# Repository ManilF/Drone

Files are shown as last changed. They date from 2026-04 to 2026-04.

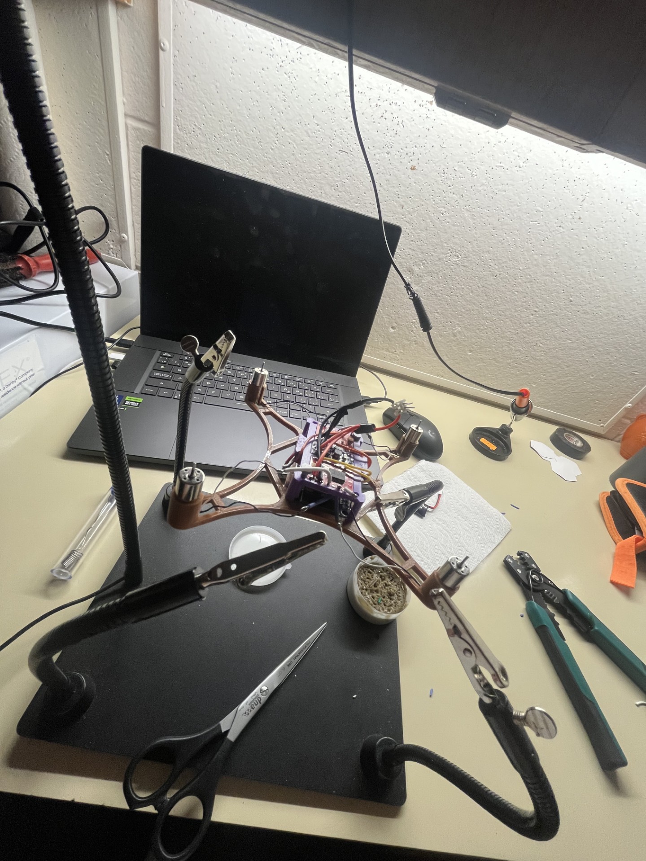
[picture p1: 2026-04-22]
Project_Gallery/image1.jpg

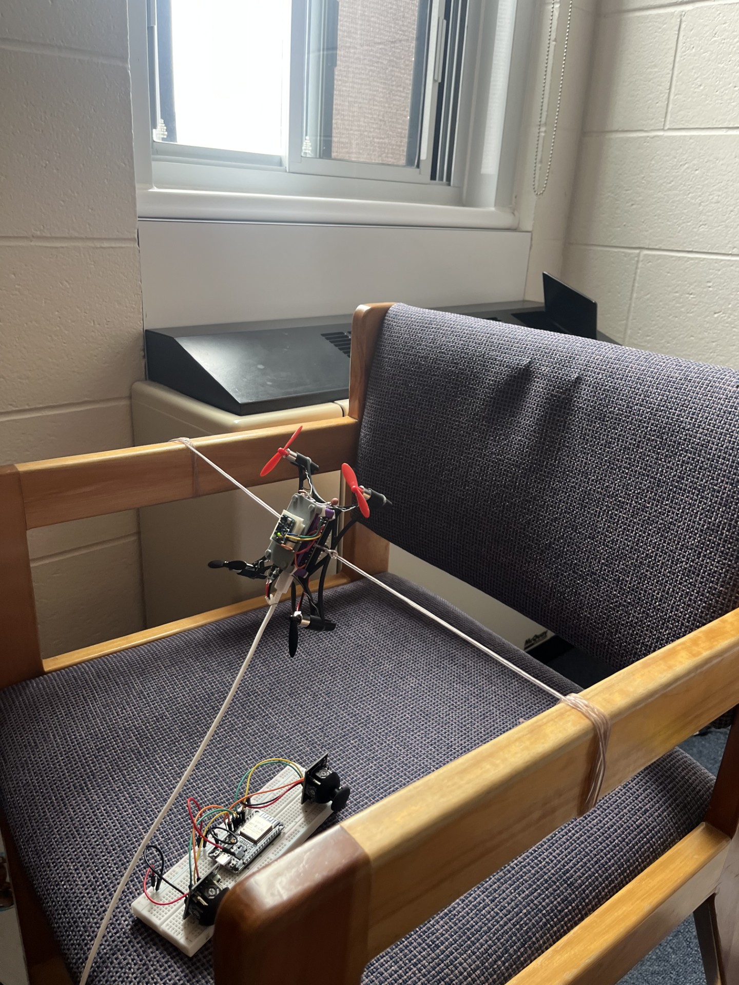
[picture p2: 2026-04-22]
Project_Gallery/image2.jpg

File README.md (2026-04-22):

# ESP32 Brushed Quadcopter

A full flight controller, a full RC radio link, and a complete ground telemetry system — built from two $5 ESP32 chips, with no flight-controller firmware, no RC receiver, no ESCs, and no external libraries beyond the ESP32 Arduino core.

Total electronics cost: **under $30**. Total code: **two `.cpp` files**. Madgwick AHRS, PID, mixer, radio protocol, all written from scratch and readable in an afternoon.

## Why This Project Is Unusual

A typical hobby quad stack is a $200+ pile of black boxes: a dedicated flight controller running Betaflight (half a million lines of C), an ELRS / Crossfire RC transmitter and receiver, four brushless ESCs running BLHeli, an OSD chip, an optional telemetry radio. You flash firmware, tune PIDs in a GUI, and learn nothing about what's actually happening inside.

This project replaces all of it with two generic WiFi microcontrollers:

| Part of the stack | Typical approach | This project |
|---|---|---|
| Flight controller | F4/F7 board + Betaflight | $5 ESP32, 1600 lines of `.cpp` |
| RC transmitter | $50–200 TX module | $5 ESP32 + 2 joysticks |
| RC protocol | ELRS / CRSF / SBUS | ESP-NOW (WiFi broadcast) |
| Receiver | Separate radio module | Same ESP32 as the FC |
| ESCs | 4x brushless ESCs, $15–30 | 2x TB6612FNG H-bridges, $2 each |
| Sensor fusion | Library / DMP | Inline Madgwick 6DOF (100 lines) |
| Telemetry | Extra hardware or none | Bidirectional over the same ESP-NOW link |

Because ESP-NOW is built into the ESP32's WiFi radio, the entire control **and** telemetry link is a software feature of the processor that was already there for IoT. Sub-millisecond latency, ~200 m line-of-sight range, no pairing ceremony, and you can OTA-reflash both ends over the same radio.

The full story (including why the educational value matters and what this unlocks): see `05_Ideas/esp32-drone-novelty-2026-04-20.md` in the Obsidian vault.

## Repository Layout

- `TX_Final.cpp` — controller / transmitter firmware
- `RX_Final.cpp` — drone / receiver firmware (the flight controller)
- `MadgwickAHRS.c` — reference implementation kept for comparison (not compiled into the flight controller — the drone uses its own inline 6DOF version)
- `CLAUDE.md` — implementation notes and “do not touch” list
- `TESTING_PLAN.md` — step-by-step PID tuning procedure

Each `.cpp` file is a standalone Arduino sketch. There is no multi-file build. Flash `TX_Final.cpp` to the controller ESP32, flash `RX_Final.cpp` to the drone ESP32.

## Hardware

### Bill of Materials (approx.)

| Part | Qty | Cost |
|---|---|---|
| ESP32 DevKit V1 | 2 | ~$10 |
| GY-87 (MPU6050 6-DOF IMU) | 1 | ~$3 |
| TB6612FNG H-bridge breakout | 2 | ~$4 |
| Brushed coreless motor (8520) | 4 | ~$4 |
| 1S LiPo (350–500 mAh) | 1 | ~$5 |
| 2x analog thumb joystick with switch | — | ~$3 |
| Frame (3D-printed or foam) + props | — | ~$2 |
| **Total** | | **~$31** |

### Drone wiring

- I2C: **SDA = GPIO22, SCL = GPIO21** (swapped vs. ESP32 default; matches this build)
- Motors via TB6612FNG:
  - M1 → **GPIO25** (front-left)
  - M2 → **GPIO26** (front-right)
  - M3 → **GPIO27** (back-right)
  - M4 → **GPIO14** (back-left)
- TB6612 STBY (both boards tied together) → **GPIO33**, with a 10 kΩ pull-down to ground so motors stay disabled during boot

### Controller wiring

All joystick axes must be on ADC1 pins — ADC2 is unusable while WiFi is active on ESP32.

| Input | GPIO |
|---|---|
| Throttle axis | 33 |
| Yaw axis | 32 |
| Pitch axis | 35 |
| Roll axis | 34 |
| Left stick switch (L_SW) | 26 |
| Right stick switch (R_SW) | 27 |
| Status LED (optional) | 2 |

## Radio Link — ESP-NOW

The drone and controller are paired by hard-coding each other’s MAC addresses.

- In `TX_Final.cpp`: `receiverMac[]` = **drone** MAC
- In `RX_Final.cpp`: `CONTROLLER_MAC[]` = **controller** MAC

First-time pairing:

1. Flash both boards once with placeholder MACs.
2. Open Serial Monitor on each at 115200 baud; the boards print their own MAC at boot.
3. Paste the drone MAC into `TX_Final.cpp` and the controller MAC into `RX_Final.cpp`.
4. Reflash.

### Packet structures

Both structs are `__attribute__((packed))` and must match byte-for-byte across both files.

- `ControlPacket` (15 bytes): `t_ms`, `armed`, `calibrate_level`, `thr (0..1000)`, `yaw/pitch/roll (-500..500)`
- `TelemetryPacket` (30 bytes): IMU angles, PID outputs, all four motor duties, accel magnitude, arming/standby state, packet age

Control packets are sent at 50 Hz; telemetry at 20 Hz. The drone disarms automatically if no valid control packet arrives for **250 ms** (failsafe).

## Firmware Architecture

### Drone main loop — 500 Hz

```
getCommandsFromEspNow()   // pull latest control packet, apply failsafe
  → getIMUdata()          // raw I2C, bias correct, LPF
  → Madgwick6DOF()        // quaternion fusion with accel-trust gating
  → getDesState()         // sticks → desired roll/pitch angles + yaw rate
  → controlANGLE()        // PID: angle mode for roll/pitch, rate mode for yaw
  → mixerQuad()           // quad-X mixer with per-motor spin sign
  → scaleToDuty()         // 0..1 → 0..255 PWM duty
  → throttleCutAndCommand()  // arm/failsafe check, write PWM
  → sendTelemetry()
```

### Control strategy

- **Roll / Pitch**: angle-mode PID. Desired state is an absolute angle in degrees. Derivative-on-measurement (uses raw gyro, not error derivative) — avoids derivative kick on setpoint changes.
- **Yaw**: rate-mode PID. Desired state is a rotation rate in deg/s. This is standard for quads because yaw has no gravity reference and you want to allow continuous spins.
- **Anti-windup**: integrators reset when throttle < 1060 (drone grounded).
- **Adaptive Madgwick beta**: normally 0.06 while armed (vibration-tolerant). When the estimator drifts >5° from the accel-only attitude and the accel reads ~1 g, beta boosts to 0.20 for fast recovery, then ramps back down.

### Mixer

```cpp
m1 = T - P + R + (M1_SPIN * Y);   // front-left
m2 = T - P - R + (M2_SPIN * Y);   // front-right
m3 = T + P - R + (M3_SPIN * Y);   // back-right
m4 = T + P + R + (M4_SPIN * Y);   // back-left
```

`M1_SPIN..M4_SPIN` are compile-time constants (`MOTOR_SPIN_CW = -1`, `MOTOR_SPIN_CCW = +1`). The default configuration is:

- M1 (FL), M3 (BR) = **CW** viewed from above
- M2 (FR), M4 (BL) = **CCW** viewed from above

If your physical motors spin the other way, **change only these four constants** — do not rewrite the mixer. Yaw authority and sign correctness follow automatically.

## Calibration

### Startup calibration (every boot)

Drone sits still for ~3 seconds after power-on. The firmware averages 800 IMU samples to compute gyro bias and accel bias along the measured gravity direction. It does **not** assume the frame is perfectly level — it only pulls the resting accel magnitude toward 1.00 g.

Keep the drone still on a flat surface during the boot LED-blink sequence.

### Level-trim gesture (in-flight re-calibration)

While **disarmed**, hold this stick combination for 3 seconds:

- Left stick: bottom-right (throttle low + yaw right)
- Right stick: bottom-left (pitch low + roll left)

The controller sets `calibrate_level = 1` in the outgoing packet. The drone runs a still-IMU calibration and stores the current pose as “this is level” — useful when the drone develops a small steady lean.

### Stick-center calibration

On controller boot, the ESP32 samples the joystick analog centers. Keep both sticks centered while the controller boots.

## Diagnostic Modes

Compile-time flags at the top of `RX_Final.cpp`:

- `MOTOR_ISOLATION_MODE = 1` — bypasses stabilization and drives **one motor at a time** by stick position. THROTTLE stick → M1, YAW → M2, ROLL → M3, PITCH → M4. Use this to verify which GPIO goes to which physical corner, and to confirm each motor’s spin direction.
- `ALL_MOTORS_SAME_THRUST_MODE = 1` — drives all four motors at the throttle value, no stabilization. Use this to confirm that the frame lifts straight up (any lean isolates a thrust or CG issue, not a PID issue).
- `PRINT_TEL_ON_USB = 1` — detailed USB serial telemetry at 20 Hz for debugging PID/IMU behavior.

**Use diagnostic modes with props off.**

## Safety

- Pull-down resistor on `STBY_PIN` (10 kΩ) so the TB6612 drivers stay disabled during ESP32 boot.
- Failsafe: 250 ms without a valid control packet → auto-disarm + throttle cut.
- Arming requires throttle already low (< 1100).
- Disarm cuts `STBY` (hard motor disable) and zeroes all PWM outputs.
- Props off for first flash, first wiring check, first MAC pairing, and every diagnostic mode.
- Verify motor spin directions match `M1_SPIN..M4_SPIN` **before** enabling yaw. A mismatch turns the yaw loop into positive feedback and the drone will shoot to a corner.

## Build & Flash

- Arduino IDE with ESP32 board support, or PlatformIO with an ESP32 target
- Board: **ESP32 Dev Module**
- Baud: **115200**
- Dependencies: none beyond the ESP32 Arduino core (`Arduino.h`, `Wire.h`, `WiFi.h`, `esp_now.h`)

## Tuning

Current gains (in `RX_Final.cpp`):

- Roll / Pitch: `Kp=0.33`, `Ki=0.18`, `Kd=0.06`
- Yaw: `Kp=0.005`, `Ki=0`, `Kd=0`, output clamped to `±0.08`

Follow `TESTING_PLAN.md` for the step-by-step bring-up procedure (props-off checks → equal-thrust lift test → low hover → increasing Kp until oscillation → adding Ki → adding Kd).

## Known Assumptions

- PWM: 20 kHz, 8-bit resolution
- Control loop: 500 Hz target
- No altitude hold — pure manual throttle
- No magnetometer — yaw is rate-controlled, not heading-held
- Yaw authority depends on `M1_SPIN..M4_SPIN` matching physical hardware

## Next Improvements

- Altitude hold using the BMP180 that’s already on the GY-87 board (currently unused)
- Position hold with a PMW3901 optical flow sensor (~$5)
- Web-based PID tuning GUI served from the ESP32’s WiFi AP
- Multi-drone ESP-NOW swarm — one controller, many drones
- Automated PID tuning (relay method or Ziegler-Nichols)

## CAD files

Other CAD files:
.ipt files/Part1.ipt
.ipt files/Part3.ipt
.ipt files/Part4.ipt
.ipt files/head_2.675.ipt
.ipt files/screw_2.75mm.ipt

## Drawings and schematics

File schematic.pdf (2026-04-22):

# GND VCC_IN

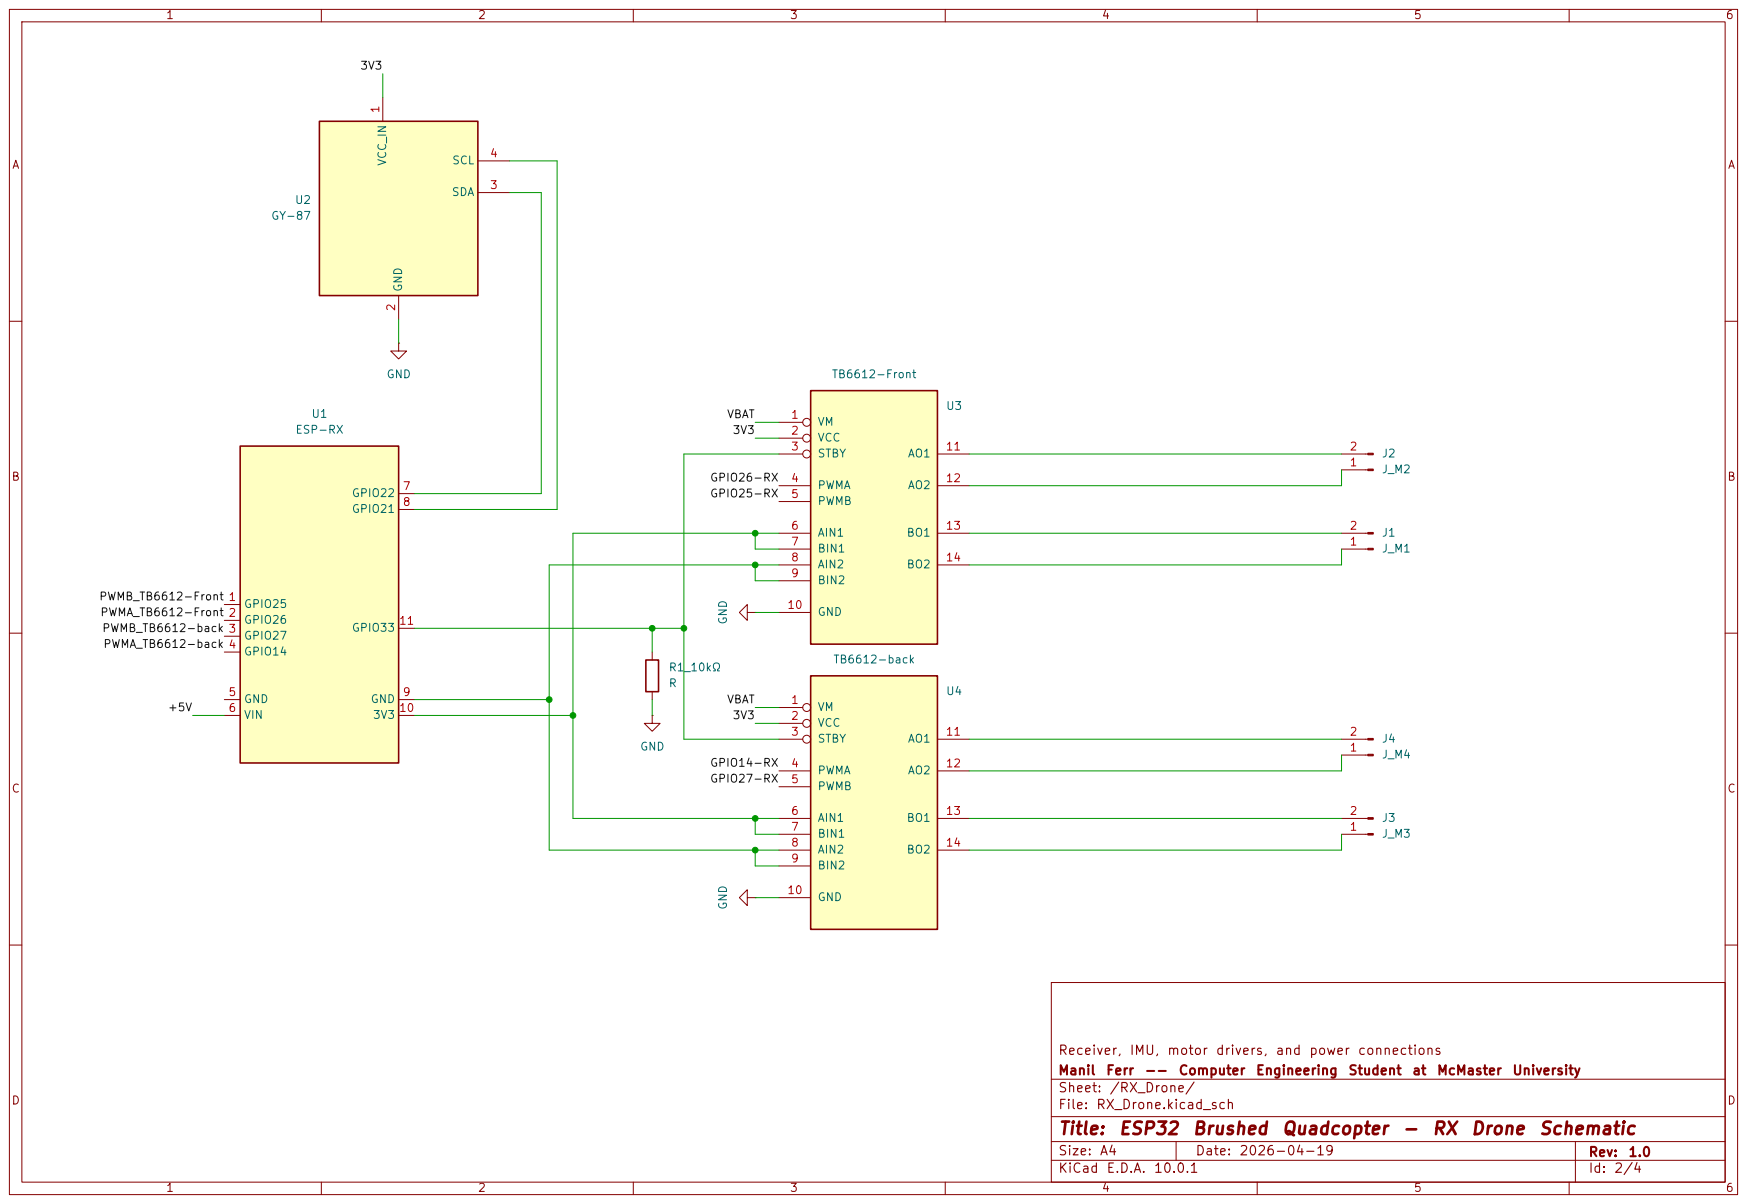
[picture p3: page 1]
D Date: 2026-04-19; Size: A4; Rev: 1.0; GND; 1 GND; SDA; SCL; VM 1 VCC 2; STBY 3; PWMA 4; PWMB 5; AIN1 6; BIN1 7; AIN2 8; BIN2 9; GND 10; TB6612-Front GND; TB6612-back GPIO25 1 GPIO26 2 GPIO27 3 GPIO14 4 GND 5; VIN 6; GPIO22 7 GPIO21 8 GND 9; 3V3 10 GPIO33 11 U1; ESP-RX PWMB_TB6612-Front; GPIO27-RX GPIO14-RX; GPIO26-RX GPIO25-RX; VBAT 3V3

VBAT PWMA_TB6612-back PWMB_TB6612-back PWMA_TB6612-Front +5V

Receiver, IMU, motor drivers, and power connections GND

Manil Ferr -- Computer Engineering Student at McMaster University
Sheet: /RX_Drone/
File: RX_Drone.kicad_sch
Title: ESP32 Brushed Quadcopter - RX Drone Schematic
KiCad E.D.A. 10.0.1

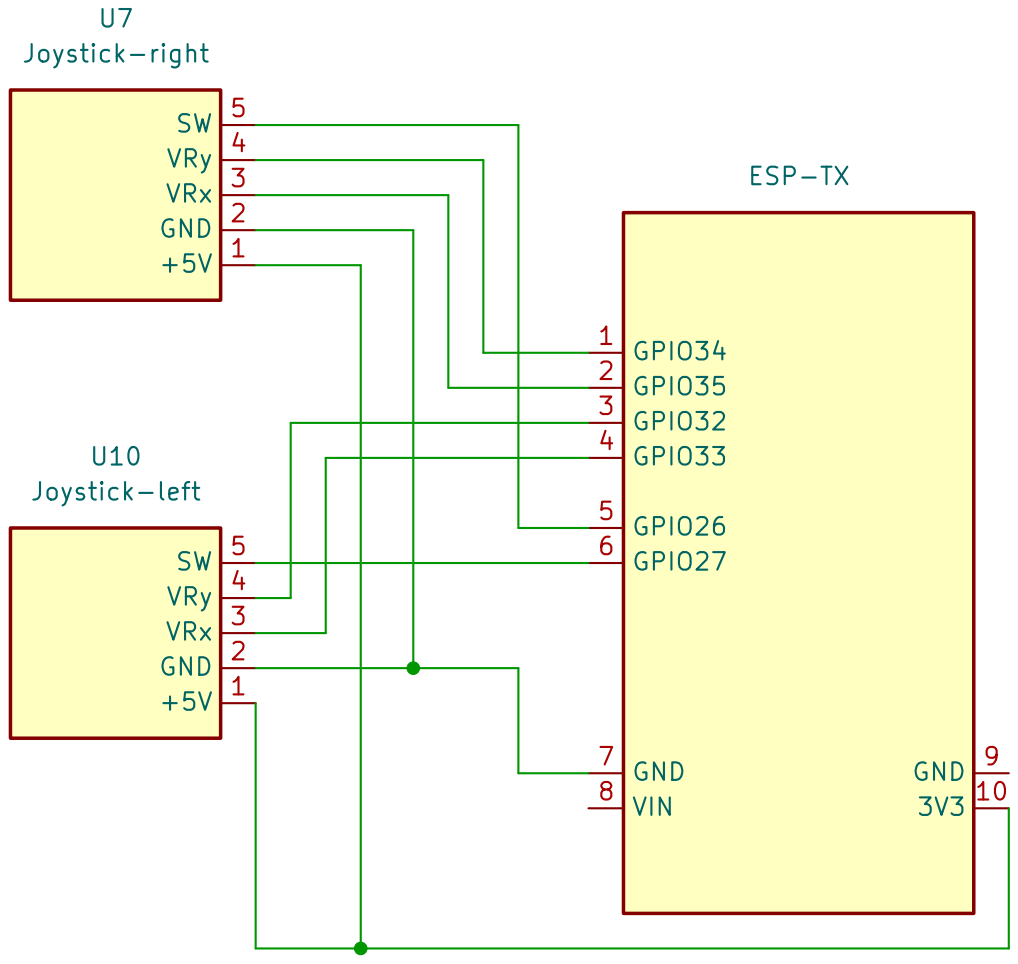
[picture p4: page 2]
D Date: 2026-04-19; VRx 3; VRy 4; Joystick-right; GPIO34 1 GPIO35 2 GPIO32 3 GPIO33 4 GPIO26 5 GPIO27 6 GND 7; VIN 8; GND 9; ESP-TX

Joystick-left +5V 1 GND 2

VRy 4
VRx 3
Transmitter ESP32, joysticks, and switch connections ⁺⁵V 1 GND 2

Manil Ferr -- Computer Engineering Student at McMaster University
Sheet: /TX_Controller/
File: TX_Controller.kicad_sch
Title: ESP32 Brushed Quadcopter - TX Controller Schematic

AB

C

D

AB

C

### D Date: 2026-04-19

# Title: ESP32 Brushed Quadcopter - Power Schematic

### File: Power.kicad_sch

### Sheet: /Power/

## Manil Ferr -- Computer Engineering Student at McMaster University

### Battery input and boost converter V IN+ 1

V IN- 2

V OUT- | 3
V OUT+ | 4 U5 Boost_Converter_Module BT1 Battery_Cell | +5V GND

GND

VBAT

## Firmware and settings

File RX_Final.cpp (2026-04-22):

/*
  Project: ESP32 Brushed Quadcopter Flight Controller
  File: RX_Final.cpp
  Author: Ferr Manil
  Role: First Year Computer Engineering Student at McMaster University

  Description:
  This file implements the drone-side flight controller for a custom low-cost
  brushed quadcopter. It receives pilot commands over ESP-NOW, reads and filters
  MPU6050 IMU data, estimates attitude with a 6DOF Madgwick-based pipeline,
  applies roll/pitch angle PID and yaw rate PID control, mixes commands for four
  brushed motors, and returns telemetry to the transmitter.
*/


  #include <Arduino.h>
  #include <Wire.h>
  #include <WiFi.h>
  #include <esp_now.h>

  #define MOTOR_ISOLATION_MODE 0

  #define ALL_MOTORS_SAME_THRUST_MODE 0

  #define PRINT_TEL_ON_USB 1

  static const int LOOP_HZ = 500;

  static const int PWM_FREQ = 20000;
  static const int PWM_RES  = 8;

  static const int M1_PIN = 25;
  static const int M2_PIN = 26;
  static const int M3_PIN = 27;
  static const int M4_PIN = 14;

  static const int STBY_PIN = 33;

  static const int I2C_SDA_PIN = 22;
  static const int I2C_SCL_PIN = 21;

  enum MotorSpinDirection : int8_t {
    MOTOR_SPIN_CW  = -1,
    MOTOR_SPIN_CCW =  1,
  };
  static inline const char* motorSpinName(MotorSpinDirection dir) {
    return (dir == MOTOR_SPIN_CCW) ? "CCW" : "CW";
  }
  static const MotorSpinDirection M1_SPIN = MOTOR_SPIN_CW;
  static const MotorSpinDirection M2_SPIN = MOTOR_SPIN_CCW;
  static const MotorSpinDirection M3_SPIN = MOTOR_SPIN_CW;
  static const MotorSpinDirection M4_SPIN = MOTOR_SPIN_CCW;

  static const uint32_t FAILSAFE_MS = 250;

  float i_limit   = 25.0f;
  float maxRoll   = 30.0f;
  float maxPitch  = 30.0f;
  float maxYaw    = 160.0f;

  float Kp_roll_angle  = 0.33f;    
  float Ki_roll_angle  = 0.18f;   
  float Kd_roll_angle  = 0.06f;    
  float Kp_pitch_angle = 0.33f;    
  float Ki_pitch_angle = 0.18f;    
  float Kd_pitch_angle = 0.06f;    

  float Kp_yaw = 0.005;
  float Ki_yaw = 0.0f;
  float Kd_yaw = 0.00f;
  float yaw_pid_limit = 0.08f;

  float B_madgwick_armed    = 0.06f;
  float B_madgwick_disarmed = 0.50f;
  float B_accel    = 0.27f;
  float B_gyro     = 0.10f;

  float B_madgwick_recovery  = 0.20f;
  float recovery_threshold_deg = 5.0f;
  float recovery_ramp_rate   = 0.01f;

  int MIN_DUTY_WHEN_RUNNING = 0;

  float accMag_g = 1.0f;
  float accTrustWeight = 1.0f;
  float accRejectPct = 0.0f;
  float currentBeta = 0.02f;

  static const float ACC_TRUST_HARD_LOW_G  = 0.70f;
  static const float ACC_TRUST_HARD_HIGH_G = 1.30f;
  static const float ACC_TRUST_SOFT_ERR_G  = 0.25f;

  static const int STARTUP_IMU_CAL_DISCARD_SAMPLES = 100;
  static const int STARTUP_IMU_CAL_SAMPLES         = 800;
  static const int STARTUP_IMU_CAL_DELAY_MS        = 2;
  static const int LEVEL_CAPTURE_DISCARD_SAMPLES   = 30;
  static const int LEVEL_CAPTURE_SAMPLES           = 80;

  static uint8_t CONTROLLER_MAC[6] = {0x4C,0xC3,0x82,0xDA,0xF8,0x38};

  struct __attribute__((packed)) ControlPacket {
    uint32_t t_ms;
    uint8_t  armed;
    uint8_t  calibrate_level;
    int16_t  thr;
    int16_t  yaw;
    int16_t  pitch;
    int16_t  roll;
  };

  struct __attribute__((packed)) TelemetryPacket {
    uint32_t t_ms;
    uint8_t  seq;
    uint8_t  rx_ok;
    uint16_t rx_age_ms;

    uint8_t  armed_cmd;
    uint8_t  armedFly;
    uint8_t  stby;
    uint8_t  reserved0;

    int16_t  thr, yaw, pitch, roll;

    int16_t  roll_imu_cdeg;
    int16_t  pitch_imu_cdeg;

    int16_t  roll_pid_milli;
    int16_t  pitch_pid_milli;
    int16_t  yaw_pid_milli;

    uint8_t  m1_command_PWM, m2_command_PWM, m3_command_PWM, m4_command_PWM;
    uint16_t acc_mg;
  };

  static portMUX_TYPE packetMux = portMUX_INITIALIZER_UNLOCKED;
  static ControlPacket lastPacket{};
  static uint32_t lastPacketRxMs = 0;
  static bool havePacket = false;

  static void onEspNowRecv(const esp_now_recv_info_t *info, const uint8_t *data, int len) {
    (void)info;
    

    if (len != (int)sizeof(ControlPacket)) return;
    

    portENTER_CRITICAL(&packetMux);
    memcpy(&lastPacket, data, sizeof(ControlPacket));
    lastPacketRxMs = millis();
    havePacket = true;
    portEXIT_CRITICAL(&packetMux);
  }

  static bool getLatestPacket(void *outBuf, size_t outSize, uint32_t &ageMs) {
    uint32_t rxMs;
    bool ok;
    

    portENTER_CRITICAL(&packetMux);
    if (outBuf != nullptr && outSize >= sizeof(ControlPacket)) {
      memcpy(outBuf, &lastPacket, sizeof(ControlPacket));
    }
    rxMs = lastPacketRxMs;
    ok = havePacket;
    portEXIT_CRITICAL(&packetMux);
    

    uint32_t now = millis();
    ageMs = ok ? (now - rxMs) : 0xFFFFFFFFu;
    return ok;
  }

  static const uint8_t MPU_ADDR       = 0x68;
  static const uint8_t REG_WHOAMI     = 0x75;
  static const uint8_t REG_PWR_MGMT_1 = 0x6B;
  static const uint8_t REG_SMPLRT_DIV = 0x19;
  static const uint8_t REG_CONFIG     = 0x1A;
  static const uint8_t REG_GYRO_CFG   = 0x1B;
  static const uint8_t REG_ACCEL_CFG  = 0x1C;
  static const uint8_t REG_DATA       = 0x3B;

  static const float GYRO_SCALE_FACTOR  = 131.0f;
  static const float ACCEL_SCALE_FACTOR = 16384.0f;

  static bool i2cWriteByte(uint8_t addr, uint8_t reg, uint8_t val) {
    Wire.beginTransmission(addr);
    Wire.write(reg);
    Wire.write(val);
    return Wire.endTransmission() == 0;
  }

  static bool i2cReadBytes(uint8_t addr, uint8_t reg, uint8_t *buf, size_t n) {
    Wire.beginTransmission(addr);
    Wire.write(reg);
    if (Wire.endTransmission(false) != 0) return false;
    

    size_t got = Wire.requestFrom((int)addr, (int)n, (int)true);
    if (got != n) return false;
    

    for (size_t i=0;i<n;i++) buf[i] = Wire.read();
    return true;
  }

  static bool mpuInit() {
    uint8_t who=0;
    

    if (!i2cReadBytes(MPU_ADDR, REG_WHOAMI, &who, 1)) return false;
    if (who != 0x68) return false;
    

    if (!i2cWriteByte(MPU_ADDR, REG_PWR_MGMT_1, 0x00)) return false;
    delay(50);
    

    i2cWriteByte(MPU_ADDR, REG_SMPLRT_DIV, 0x00);
    

    i2cWriteByte(MPU_ADDR, REG_CONFIG, 0x03);
    

    i2cWriteByte(MPU_ADDR, REG_GYRO_CFG, 0x00);
    

    i2cWriteByte(MPU_ADDR, REG_ACCEL_CFG, 0x00);
    
    delay(10);
    return true;
  }

  static bool mpuReadRaw(int16_t &ax, int16_t &ay, int16_t &az, int16_t &gx, int16_t &gy, int16_t &gz) {
    uint8_t b[14];
    

    if (!i2cReadBytes(MPU_ADDR, REG_DATA, b, 14)) return false;
    

    ax = (int16_t)((b[0]<<8)  | b[1]);
    ay = (int16_t)((b[2]<<8)  | b[3]);
    az = (int16_t)((b[4]<<8)  | b[5]);
    gx = (int16_t)((b[8]<<8)  | b[9]);
    gy = (int16_t)((b[10]<<8) | b[11]);
    gz = (int16_t)((b[12]<<8) | b[13]);
    return true;
  }

  static void Madgwick6DOF(float gx, float gy, float gz, float ax, float ay, float az, float dt);
  static void getIMUdata();

  float dt = 0.0f;
  uint32_t prev_time = 0;

  float channel_1_pwm = 1000.0f;
  float channel_2_pwm = 1500.0f;
  float channel_3_pwm = 1500.0f;
  float channel_4_pwm = 1500.0f;
  float channel_5_pwm = 2000.0f;
  const float channel_1_fs = 1000.0f;
  const float channel_2_fs = 1500.0f;
  const float channel_3_fs = 1500.0f;
  const float channel_4_fs = 1500.0f;
  const float channel_5_fs = 2000.0f;

  float AccX=0, AccY=0, AccZ=0;
  float GyroX=0, GyroY=0, GyroZ=0;

  float AccX_prev=0, AccY_prev=0, AccZ_prev=0;
  float GyroX_prev=0, GyroY_prev=0, GyroZ_prev=0;

  float AccErrorX = 0.0f, AccErrorY = 0.0f, AccErrorZ = 0.0f;
  float GyroErrorX = 0.0f, GyroErrorY = 0.0f, GyroErrorZ = 0.0f;

  float roll_IMU=0, pitch_IMU=0, yaw_IMU=0;
  float q0=1, q1=0, q2=0, q3=0;
  float levelRollTrimDeg = 0.0f;
  float levelPitchTrimDeg = 0.0f;
  bool calibrateLevelCmd = false;
  bool prevCalibrateLevelCmd = false;

  float thro_des=0;
  float roll_des=0;
  float pitch_des=0;
  float yaw_des=0;

  float error_roll=0;
  float integral_roll=0;
  float derivative_roll=0;
  float roll_PID=0;

  float error_pitch=0;
  float integral_pitch=0;
  float derivative_pitch=0;
  float pitch_PID=0;

  float error_yaw=0;
  float error_yaw_prev=0;
  float integral_yaw=0;
  float derivative_yaw=0;
  float yaw_PID=0;

  float m1_command_scaled=0, m2_command_scaled=0, m4_command_scaled=0, m3_command_scaled=0;
  int m1_command_PWM=0, m2_command_PWM=0, m4_command_PWM=0, m3_command_PWM=0;

  bool armedFly = false;

  static bool calibrateImuStill() {
    float sumAx = 0.0f, sumAy = 0.0f, sumAz = 0.0f;
    float sumGx = 0.0f, sumGy = 0.0f, sumGz = 0.0f;
    int validSamples = 0;

    for (int i = 0; i < STARTUP_IMU_CAL_DISCARD_SAMPLES + STARTUP_IMU_CAL_SAMPLES; ++i) {
      int16_t axRaw, ayRaw, azRaw, gxRaw, gyRaw, gzRaw;
      if (mpuReadRaw(axRaw, ayRaw, azRaw, gxRaw, gyRaw, gzRaw)) {
        if (i >= STARTUP_IMU_CAL_DISCARD_SAMPLES) {
          sumAx += (float)axRaw / ACCEL_SCALE_FACTOR;
          sumAy += (float)ayRaw / ACCEL_SCALE_FACTOR;
          sumAz += (float)azRaw / ACCEL_SCALE_FACTOR;
          sumGx += (float)gxRaw / GYRO_SCALE_FACTOR;
          sumGy += (float)gyRaw / GYRO_SCALE_FACTOR;
          sumGz += (float)gzRaw / GYRO_SCALE_FACTOR;
          ++validSamples;
        }
      }
      delay(STARTUP_IMU_CAL_DELAY_MS);
    }

    if (validSamples < (STARTUP_IMU_CAL_SAMPLES / 2)) {
      return false;
    }

    const float invCount = 1.0f / (float)validSamples;
    const float avgAx = sumAx * invCount;
    const float avgAy = sumAy * invCount;
    const float avgAz = sumAz * invCount;
    const float avgGx = sumGx * invCount;
    const float avgGy = sumGy * invCount;
    const float avgGz = sumGz * invCount;
    const float avgAccNorm = sqrtf(avgAx*avgAx + avgAy*avgAy + avgAz*avgAz);

    GyroErrorX = avgGx;
    GyroErrorY = avgGy;
    GyroErrorZ = avgGz;

    if (avgAccNorm > 0.80f && avgAccNorm < 1.20f) {
      const float gravityBias = avgAccNorm - 1.0f;
      const float gravityDirX = avgAx / avgAccNorm;
      const float gravityDirY = avgAy / avgAccNorm;
      const float gravityDirZ = avgAz / avgAccNorm;

      AccErrorX = gravityBias * gravityDirX;
      AccErrorY = gravityBias * gravityDirY;
      AccErrorZ = gravityBias * gravityDirZ;
    } else {
      AccErrorX = 0.0f;
      AccErrorY = 0.0f;
      AccErrorZ = 0.0f;
    }

    AccX_prev = avgAx - AccErrorX;
    AccY_prev = avgAy - AccErrorY;
    AccZ_prev = avgAz - AccErrorZ;
    GyroX_prev = 0.0f;
    GyroY_prev = 0.0f;
    GyroZ_prev = 0.0f;
    accMag_g = sqrtf(AccX_prev*AccX_prev + AccY_prev*AccY_prev + AccZ_prev*AccZ_prev);

    Serial.printf(
      "Still IMU calibration: accNormRaw=%.3f g accNormCorrected=%.3f g | accBias=%.4f,%.4f,%.4f g | gyroBias=%.3f,%.3f,%.3f dps\n",
      avgAccNorm,
      accMag_g,
      AccErrorX, AccErrorY, AccErrorZ,
      GyroErrorX, GyroErrorY, GyroErrorZ
    );

    return true;
  }

  static float invSqrt(float x) { return 1.0f / sqrtf(x); }

  static void Madgwick6DOF(float gx, float gy, float gz, float ax, float ay, float az, float dt) {
    float recipNorm;
    float s0, s1, s2, s3;
    float qDot1, qDot2, qDot3, qDot4;
    float _2q0, _2q1, _2q2, _2q3, _4q0, _4q1, _4q2 ,_8q1, _8q2, q0q0, q1q1, q2q2, q3q3;

    gx *= 0.0174533f;
    gy *= 0.0174533f;
    gz *= 0.0174533f;

    qDot1 = 0.5f * (-q1 * gx - q2 * gy - q3 * gz);
    qDot2 = 0.5f * ( q0 * gx + q2 * gz - q3 * gy);
    qDot3 = 0.5f * ( q0 * gy - q1 * gz + q3 * gx);
    qDot4 = 0.5f * ( q0 * gz + q1 * gy - q2 * gx);

    float accMag = sqrtf(ax*ax + ay*ay + az*az);

    float accW = 1.0f;
    if (accMag < ACC_TRUST_HARD_LOW_G || accMag > ACC_TRUST_HARD_HIGH_G) {
      accW = 0.0f;
    } else {

      float err = fabsf(accMag - 1.0f);
      accW = 1.0f - (err / ACC_TRUST_SOFT_ERR_G);
      accW = constrain(accW, 0.0f, 1.0f);
    }

    accTrustWeight = accW;
    accRejectPct = (1.0f - accW) * 100.0f;

    

    if (!((ax == 0.0f) && (ay == 0.0f) && (az == 0.0f))) {

      recipNorm = invSqrt(ax*ax + ay*ay + az*az);
      ax *= recipNorm;
      ay *= recipNorm;
      az *= recipNorm;

      _2q0 = 2.0f*q0;
      _2q1 = 2.0f*q1;
      _2q2 = 2.0f*q2;
      _2q3 = 2.0f*q3;
      _4q0 = 4.0f*q0;
      _4q1 = 4.0f*q1;
      _4q2 = 4.0f*q2;
      _8q1 = 8.0f*q1;
      _8q2 = 8.0f*q2;
      q0q0 = q0*q0;
      q1q1 = q1*q1;
      q2q2 = q2*q2;
      q3q3 = q3*q3;

      s0 = _4q0*q2q2 + _2q2*ax + _4q0*q1q1 - _2q1*ay;
      s1 = _4q1*q3q3 - _2q3*ax + 4.0f*q0q0*q1 - _2q0*ay - _4q1 + _8q1*q1q1 + _8q1*q2q2 + _4q1*az;
      s2 = 4.0f*q0q0*q2 + _2q0*ax + _4q2*q3q3 - _2q3*ay - _4q2 + _8q2*q1q1 + _8q2*q2q2 + _4q2*az;
      s3 = 4.0f*q1q1*q3 - _2q1*ax + 4.0f*q2q2*q3 - _2q2*ay;

      recipNorm = invSqrt(s0*s0 + s1*s1 + s2*s2 + s3*s3);
      s0 *= recipNorm;
      s1 *= recipNorm;
      s2 *= recipNorm;
      s3 *= recipNorm;

      float betaBase;
      if (!armedFly) {
        betaBase = B_madgwick_disarmed;
        currentBeta = B_madgwick_armed;
      } else {

        float accelRoll  = atan2f(ay, az) * 57.29577951f;
        float accelPitch = -atan2f(-ax, sqrtf(ay*ay + az*az)) * 57.29577951f;
        float errDeg = max(fabsf(roll_IMU - accelRoll), fabsf(pitch_IMU - accelPitch));

        if (accW > 0.8f && errDeg > recovery_threshold_deg) {
          currentBeta = B_madgwick_recovery;
        } else {
          currentBeta -= recovery_ramp_rate;
          if (currentBeta < B_madgwick_armed) currentBeta = B_madgwick_armed;
        }
        betaBase = currentBeta;
      }
      float betaEff = betaBase * accW;
      qDot1 -= betaEff*s0;
      qDot2 -= betaEff*s1;
      qDot3 -= betaEff*s2;
      qDot4 -= betaEff*s3;
    }

    q0 += qDot1 * dt;
    q1 += qDot2 * dt;
    q2 += qDot3 * dt;
    q3 += qDot4 * dt;

    recipNorm = invSqrt(q0*q0 + q1*q1 + q2*q2 + q3*q3);
    q0 *= recipNorm;
    q1 *= recipNorm;
    q2 *= recipNorm;
    q3 *= recipNorm;

    roll_IMU  = atan2f(q0*q1 + q2*q3, 0.5f - q1*q1 - q2*q2) * 57.29577951f;
    pitch_IMU = asinf(constrain(-2.0f*(q1*q3 - q0*q2), -0.999999f, 0.999999f)) * 57.29577951f;
    yaw_IMU   = atan2f(q1*q2 + q0*q3, 0.5f - q2*q2 - q3*q3) * 57.29577951f;
  }

  static void getIMUdata() {
    int16_t ax,ay,az,gx,gy,gz;
    if (!mpuReadRaw(ax,ay,az,gx,gy,gz)) return;

    AccX = (float)ax  / ACCEL_SCALE_FACTOR;
    AccY = (float)ay  / ACCEL_SCALE_FACTOR;
    AccZ = (float)az  / ACCEL_SCALE_FACTOR;
    GyroX = (float)gx / GYRO_SCALE_FACTOR;
    GyroY = (float)gy / GYRO_SCALE_FACTOR;
    GyroZ = (float)gz / GYRO_SCALE_FACTOR;

    AccX -= AccErrorX; AccY -= AccErrorY; AccZ -= AccErrorZ;
    GyroX -= GyroErrorX; GyroY -= GyroErrorY; GyroZ -= GyroErrorZ;

    AccX = (1.0f - B_accel)*AccX_prev + B_accel*AccX;
    AccY = (1.0f - B_accel)*AccY_prev + B_accel*AccY;
    AccZ = (1.0f - B_accel)*AccZ_prev + B_accel*AccZ;
    AccX_prev = AccX; AccY_prev = AccY; AccZ_prev = AccZ;

    GyroX = (1.0f - B_gyro)*GyroX_prev + B_gyro*GyroX;
    GyroY = (1.0f - B_gyro)*GyroY_prev + B_gyro*GyroY;
    GyroZ = (1.0f - B_gyro)*GyroZ_prev + B_gyro*GyroZ;
    GyroX_prev = GyroX; GyroY_prev = GyroY; GyroZ_prev = GyroZ;

    accMag_g = sqrtf(AccX*AccX + AccY*AccY + AccZ*AccZ);

  }

  static void getCommandsFromEspNow() {
    ControlPacket p{};
    uint32_t age;
    bool ok = getLatestPacket(&p, sizeof(p), age);

    if (!ok || age > FAILSAFE_MS) {

      channel_1_pwm = channel_1_fs;
      channel_2_pwm = channel_2_fs;
      channel_3_pwm = channel_3_fs;
      channel_4_pwm = channel_4_fs;
      channel_5_pwm = channel_5_fs;
      armedFly = false;
      calibrateLevelCmd = false;
      return;
    }

    int16_t thr   = constrain((int)p.thr,   0, 1000);
    int16_t roll  = constrain((int)p.roll,  -500, 500);
    int16_t pitch = constrain((int)p.pitch, -500, 500);
    int16_t yaw   = constrain((int)p.yaw,   -500, 500);

    channel_1_pwm = 1000.0f + (float)thr;
    channel_2_pwm = 1500.0f + (float)roll;
    channel_3_pwm = 1500.0f + (float)pitch;
    channel_4_pwm = 1500.0f + (float)yaw;

    bool pktArmed = (p.armed != 0);
    channel_5_pwm = pktArmed ? 1000.0f : 2000.0f;
    calibrateLevelCmd = (!pktArmed) && (p.calibrate_level != 0);

    if (!pktArmed) {
      armedFly = false;
    } else if (!armedFly) {
      if (channel_1_pwm < 1100.0f) armedFly = true;
    }
  }

  static void applyLevelTrimToAttitude() {
    roll_IMU -= levelRollTrimDeg;
    pitch_IMU -= levelPitchTrimDeg;
  }

  static inline float bodyRollRateDps()  { return -GyroY; }
  static inline float bodyPitchRateDps() { return  GyroX; }
  static inline float bodyYawRateDps()   { return -GyroZ; }

  static inline void getBodyAccelG(float &axBody, float &ayBody, float &azBody) {
    axBody = -AccY;
    ayBody =  AccX;
    azBody =  AccZ;
  }

  static inline void getBodyGyroDps(float &gxBody, float &gyBody, float &gzBody) {
    gxBody = bodyRollRateDps();
    gyBody = bodyPitchRateDps();
    gzBody = bodyYawRateDps();
  }

  static void seedAttitudeFromCurrentAccel() {

    float ax, ay, az;
    getBodyAccelG(ax, ay, az);

    const float norm = sqrtf(ax*ax + ay*ay + az*az);
    if (norm < 0.5f) {
      q0 = 1.0f; q1 = 0.0f; q2 = 0.0f; q3 = 0.0f;
      roll_IMU = 0.0f;
      pitch_IMU = 0.0f;
      yaw_IMU = 0.0f;
      return;
    }

    ax /= norm;
    ay /= norm;
    az /= norm;

    const float rollRad = atan2f(ay, az);
    const float pitchRad = atan2f(-ax, sqrtf(ay*ay + az*az));
    const float yawRad = 0.0f;

    const float cr = cosf(rollRad * 0.5f);
    const float sr = sinf(rollRad * 0.5f);
    const float cp = cosf(pitchRad * 0.5f);
    const float sp = sinf(pitchRad * 0.5f);
    const float cy = cosf(yawRad * 0.5f);
    const float sy = sinf(yawRad * 0.5f);

    q0 = cr*cp*cy + sr*sp*sy;
    q1 = sr*cp*cy - cr*sp*sy;
    q2 = cr*sp*cy + sr*cp*sy;
    q3 = cr*cp*sy - sr*sp*cy;

    roll_IMU  = rollRad  * 57.29577951f;
    pitch_IMU = pitchRad * 57.29577951f;
    yaw_IMU   = 0.0f;
  }

  static void refreshAttitudeEstimateFromCurrentPose() {
    getIMUdata();
    seedAttitudeFromCurrentAccel();
    applyLevelTrimToAttitude();
  }

  static bool captureAverageLevelTrim(float &rollTrimOut, float &pitchTrimOut) {
    const float settleDt = max(STARTUP_IMU_CAL_DELAY_MS, 1) * 0.001f;
    float sumRoll = 0.0f;
    float sumPitch = 0.0f;
    int validSamples = 0;

    getIMUdata();
    seedAttitudeFromCurrentAccel();

    for (int i = 0; i < LEVEL_CAPTURE_DISCARD_SAMPLES + LEVEL_CAPTURE_SAMPLES; ++i) {
      delay(STARTUP_IMU_CAL_DELAY_MS);
      getIMUdata();
      float gxBody, gyBody, gzBody;
      float axBody, ayBody, azBody;
      getBodyGyroDps(gxBody, gyBody, gzBody);
      getBodyAccelG(axBody, ayBody, azBody);
      Madgwick6DOF(gxBody, gyBody, gzBody, axBody, ayBody, azBody, settleDt);

      if (i >= LEVEL_CAPTURE_DISCARD_SAMPLES) {
        sumRoll += roll_IMU;
        sumPitch += pitch_IMU;
        ++validSamples;
      }
    }

    if (validSamples < (LEVEL_CAPTURE_SAMPLES / 2)) {
      return false;
    }

    rollTrimOut = sumRoll / (float)validSamples;
    pitchTrimOut = sumPitch / (float)validSamples;
    return true;
  }

  static void forceOutputsSafeAndResetControllers() {
    armedFly = false;
    channel_1_pwm = 1000.0f;
    channel_2_pwm = 1500.0f;
    channel_3_pwm = 1500.0f;
    channel_4_pwm = 1500.0f;
    channel_5_pwm = 2000.0f;
    thro_des = 0.0f;
    roll_des = 0.0f;
    pitch_des = 0.0f;
    yaw_des = 0.0f;
    m1_command_scaled = m2_command_scaled = m3_command_scaled = m4_command_scaled = 0.0f;
    m1_command_PWM = m2_command_PWM = m3_command_PWM = m4_command_PWM = 0;
    error_roll = 0.0f;
    error_pitch = 0.0f;
    error_yaw = 0.0f;
    error_yaw_prev = 0.0f;
    integral_roll = 0.0f;
    integral_pitch = 0.0f;
    integral_yaw = 0.0f;
    derivative_roll = 0.0f;
    derivative_pitch = 0.0f;
    derivative_yaw = 0.0f;
    roll_PID = 0.0f;
    pitch_PID = 0.0f;
    yaw_PID = 0.0f;
    currentBeta = B_madgwick_armed;

    digitalWrite(STBY_PIN, LOW);
    ledcWrite(M1_PIN, 0);
    ledcWrite(M2_PIN, 0);
    ledcWrite(M3_PIN, 0);
    ledcWrite(M4_PIN, 0);
  }

  static void maybeApplyLevelCalibration() {
    const bool canCalibrateNow = calibrateLevelCmd && !armedFly && (channel_1_pwm < 1050.0f);

    if (canCalibrateNow && !prevCalibrateLevelCmd) {
      forceOutputsSafeAndResetControllers();

  #if PRINT_TEL_ON_USB
      Serial.println("Keep the drone still: running joystick IMU + level calibration...");
  #endif

      if (calibrateImuStill()) {
        float measuredRollTrim = 0.0f;
        float measuredPitchTrim = 0.0f;
        const bool haveLevelTrim = captureAverageLevelTrim(measuredRollTrim, measuredPitchTrim);

        if (haveLevelTrim) {
          levelRollTrimDeg = measuredRollTrim;
          levelPitchTrimDeg = measuredPitchTrim;
        } else {
          levelRollTrimDeg = roll_IMU;
          levelPitchTrimDeg = pitch_IMU;
        }
        refreshAttitudeEstimateFromCurrentPose();
        if (fabsf(roll_IMU) < 0.25f) roll_IMU = 0.0f;
        if (fabsf(pitch_IMU) < 0.25f) pitch_IMU = 0.0f;
        yaw_IMU = 0.0f;
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
  void loop() {

    uint32_t current_time = micros();
    dt = (current_time - prev_time) / 1000000.0f;
    prev_time = current_time;

    getCommandsFromEspNow();

    getIMUdata();
    

    if (!armedFly) {
      seedAttitudeFromCurrentAccel();
    } else {
      float gxBody, gyBody, gzBody;
      float axBody, ayBody, azBody;
      getBodyGyroDps(gxBody, gyBody, gzBody);
      getBodyAccelG(axBody, ayBody, azBody);
      Madgwick6DOF(gxBody, gyBody, gzBody, axBody, ayBody, azBody, dt);
    }
    applyLevelTrimToAttitude();
    maybeApplyLevelCalibration();

  #if MOTOR_ISOLATION_MODE

    motorIsolationTest();
    throttleCutAndCommand();
    sendTelemetry();
    loopRate(LOOP_HZ);
    return;
  #endif

  #if ALL_MOTORS_SAME_THRUST_MODE

    allMotorsSameThrust();
    throttleCutAndCommand();
    sendTelemetry();
    loopRate(LOOP_HZ);
    return;
  #endif

    getDesState();
    

    controlANGLE();
    

    mixerQuad();
    

    scaleToDuty();
    

    throttleCutAndCommand();

    sendTelemetry();
    

    loopRate(LOOP_HZ);
  }

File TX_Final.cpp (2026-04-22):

/*
  Project: ESP32 Brushed Quadcopter Controller
  File: TX_Final.cpp
  Author: Ferr Manil
  Role: First Year Computer Engineering Student at McMaster University

  Description:
  This file implements the handheld transmitter for a custom low-cost brushed
  quadcopter. It reads two joysticks, handles arm/disarm and level-calibration
  commands, sends control packets to the drone over ESP-NOW, and prints flight
  telemetry received back from the receiver.
*/

#include <WiFi.h>
#include <esp_now.h>

#define PRINT_TEL_MONITOR_ON_USB 1
#define PRINT_TEL_PLOTTER_ON_USB 0

static const float PLOT_MAX_ROLL_DEG  = 30.0f;
static const float PLOT_MAX_PITCH_DEG = 30.0f;
static const float PLOT_MAX_YAW_DPS   = 90.0f;

#define THROTTLE_PIN 33
#define YAW_PIN      32
#define PITCH_PIN    35
#define ROLL_PIN     34

#define L_SW_PIN     26
#define R_SW_PIN     27

#define LED_PIN       2

uint8_t receiverMac[] = { 0x00, 0x70, 0x07, 0x82, 0xE0, 0xBC };

typedef struct __attribute__((packed)) {
  uint32_t t_ms;
  uint8_t  armed;
  uint8_t  calibrate_level;
  int16_t  thr;
  int16_t  yaw;
  int16_t  pitch;
  int16_t  roll;
} ControlPacket;

ControlPacket pkt;

typedef struct __attribute__((packed)) {
  uint32_t t_ms;
  uint8_t  seq;
  uint8_t  rx_ok;
  uint16_t rx_age_ms;

  uint8_t  armed_cmd;
  uint8_t  armedFly;
  uint8_t  stby;
  uint8_t  reserved0;

  int16_t  thr, yaw, pitch, roll;

  int16_t  roll_imu_cdeg;
  int16_t  pitch_imu_cdeg;

  int16_t  roll_pid_milli;
  int16_t  pitch_pid_milli;
  int16_t  yaw_pid_milli;

  uint8_t  m1_command_PWM, m2_command_PWM, m3_command_PWM, m4_command_PWM;
  uint16_t acc_mg;

} TelemetryPacket;

static TelemetryPacket lastTel;
static volatile uint32_t lastTelRxMs = 0;
static volatile bool haveTel = false;
static portMUX_TYPE telMux = portMUX_INITIALIZER_UNLOCKED;

void onEspNowRecv(const esp_now_recv_info_t *info, const uint8_t *data, int len) {
  (void)info;
  if (len != (int)sizeof(TelemetryPacket)) return;

  portENTER_CRITICAL(&telMux);
  memcpy(&lastTel, data, sizeof(TelemetryPacket));
  lastTelRxMs = millis();
  haveTel = true;
  portEXIT_CRITICAL(&telMux);
}

static bool getTelemetry(TelemetryPacket &out, uint32_t &ageMs) {
  if (!haveTel) return false;

  portENTER_CRITICAL(&telMux);
  memcpy(&out, &lastTel, sizeof(TelemetryPacket));
  ageMs = millis() - lastTelRxMs;
  portEXIT_CRITICAL(&telMux);

  return true;
}

int cThr, cYaw, cPitch, cRoll;

bool armed = false;
bool lastL = true;
bool lastR = true;
uint32_t lastToggleMs = 0;

uint32_t armGraceUntilMs = 0;

uint32_t lastSendMs = 0;

uint32_t lastPrintMs = 0;
static const uint32_t PRINT_PERIOD_MS = 100;

static const int CAL_GESTURE_THRESHOLD_RAW = 900;
static const uint32_t LEVEL_CAL_HOLD_MS = 3000;
uint32_t levelCalHoldStartMs = 0;
bool levelCalTriggeredThisHold = false;

static inline int readAnalog(int pin) { return analogRead(pin); }

static inline int16_t mapAxis(int raw, int center, bool invert=false) {
  int v = raw - center;

  if (abs(v) < 40) v = 0;

  v = constrain(v, -1800, 1800);
  long out = (long)v * 500L / 1800L;
  if (invert) out = -out;
  return (int16_t)constrain(out, -500, 500);
}

static inline int16_t mapThrottle(int raw, int center) {
  int v = raw - center;

  v = constrain(v, -1800, 1800);

  long out = (long)(v + 1800) * 1000L / 3600L;
  out = constrain(out, 0, 1000);

  if (raw < center - 120) out = 0;

  return (int16_t)out;
}

static inline float cmdToSetpointDeg(int16_t cmd, float maxAbs) {
  return constrain((float)cmd, -500.0f, 500.0f) * (maxAbs / 500.0f);
}

void calibrateCenters() {
  long sThr=0, sYaw=0, sPitch=0, sRoll=0;
  const int N = 200;

  for (int i=0; i<N; i++) {
    sThr   += readAnalog(THROTTLE_PIN);
    sYaw   += readAnalog(YAW_PIN);
    sPitch += readAnalog(PITCH_PIN);
    sRoll  += readAnalog(ROLL_PIN);
    delay(5);
  }

  cThr   = sThr / N;
  cYaw   = sYaw / N;
  cPitch = sPitch / N;
  cRoll  = sRoll / N;
}

void setup() {

  Serial.begin(115200);
  WiFi.mode(WIFI_STA);
  Serial.print("Controller MAC: ");
  Serial.println(WiFi.macAddress());

  Serial.begin(115200);
  delay(200);
  Serial.println("\nController starting... keep sticks centered for calibration.");

  pinMode(L_SW_PIN, INPUT_PULLUP);
  pinMode(R_SW_PIN, INPUT_PULLUP);

  pinMode(LED_PIN, OUTPUT);
  digitalWrite(LED_PIN, LOW);

  analogReadResolution(12);

  WiFi.mode(WIFI_STA);

  if (esp_now_init() != ESP_OK) {
    Serial.println("ESP-NOW init FAILED");
    while(true) delay(1000);
  }

  esp_now_peer_info_t peerInfo{};
  memcpy(peerInfo.peer_addr, receiverMac, 6);
  peerInfo.channel = 0;
  peerInfo.encrypt = false;

  if (esp_now_add_peer(&peerInfo) != ESP_OK) {
    Serial.println("Add peer FAILED");
    while(true) delay(1000);
  }

  esp_now_register_recv_cb(onEspNowRecv);

  calibrateCenters();
  Serial.print("Centers: thr=");   Serial.print(cThr);
  Serial.print(" yaw=");           Serial.print(cYaw);
  Serial.print(" pitch=");         Serial.print(cPitch);
  Serial.print(" roll=");          Serial.println(cRoll);

  Serial.println("Ready. Click either joystick to ARM/DISARM.");
}
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
